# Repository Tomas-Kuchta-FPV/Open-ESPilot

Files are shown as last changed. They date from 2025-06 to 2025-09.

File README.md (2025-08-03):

# Open-ESPilot

This is a community-driven hardware project focused on creating an open and accessible Flight Controller (FC).   
The main focus is on being low-cost, availability, hackability and openness!  

Most of the Ardupilot FCs on the market are released by quite a huge brands that aren't OS and they cost a lot.  
That's why I've started this project to make an open-source and low-cost FC with the community.  

The target firmware is [ArduPilot](https://ardupilot.org/), which is a powerful open-source autopilot system.  

## Core Design Ideas
- *Dev board meets flight controller* hybrid
- Keep it budget-friendly
- Readily available components
- Hackability so you can hack on your features
- ❤️ Designed with care by and for the community

## What are the goals
The main one is a reference platform for devs and hackers. Then we can move to a product for the wider public.  

With the focus being on Hackability and Openness, there are endless possibilities for creativity!  
Here are a few ideas:
 - Prototyping and experimentation  
 - A low-cost alternative for those priced out of commercial FCs  
 - Teaching control theory and autonomous systems in schools  

## Why did I make it
I have a lot of experience with FPV drones running Betaflight.  

Then I started playing with the ESP32-based ArduPilot for almost three years. All of them were for a competition called Robotem Rovne.  
 - The first one is an autonomous rover which was breadboarded together. As with any other breadboard project, the wires were loose, they didn't make contact, and they were falling off.  
 - Then I made a second rover with an FC soldered on a proto board. Which worked wonderfully!  
 - Then I tried to make a PCB with a brushed motor controller. Not going to talk about this one. Didn't go as planned. :(  
 - After that, I've bought a SpeedyBee f405 WING FC and mounted it to an RC car. This is my Ardupilot learning platform.  

And now we are here. ...  
That was when I had the idea of making an ESP32 Flight Controller.  

## Future development
This is the first FC I made with the help of the community, so huge thanks to *everyone*. ♥️

### Ideas for future
 - modular system (eg, ELRS, GPS modules)
 - 30x30 FC for FPV drones. That's harder as there are plenty of great cheap FCs

## Project Status
**I have the PCB made, and now I need to order everything and test it!**
| PCB | Render |
| --- | --- |
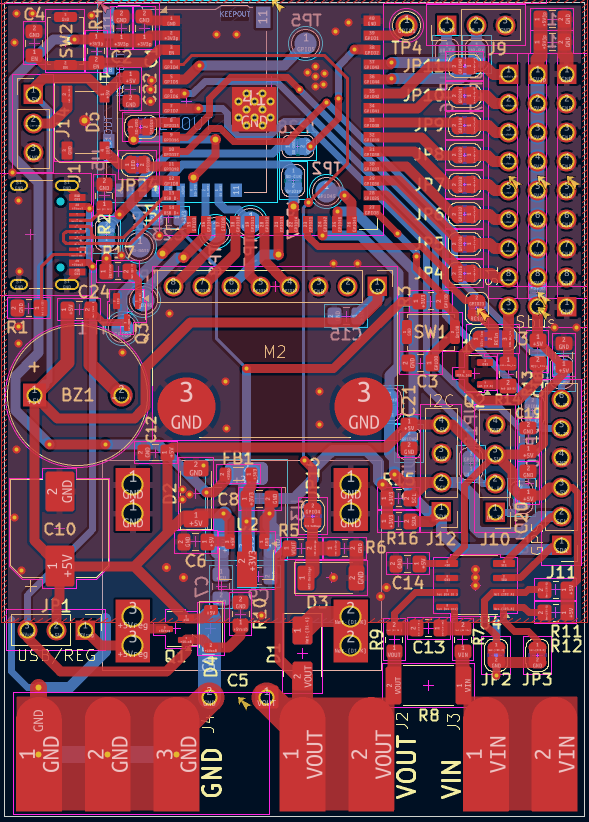
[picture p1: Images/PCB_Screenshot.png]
PCB Screenshot Front
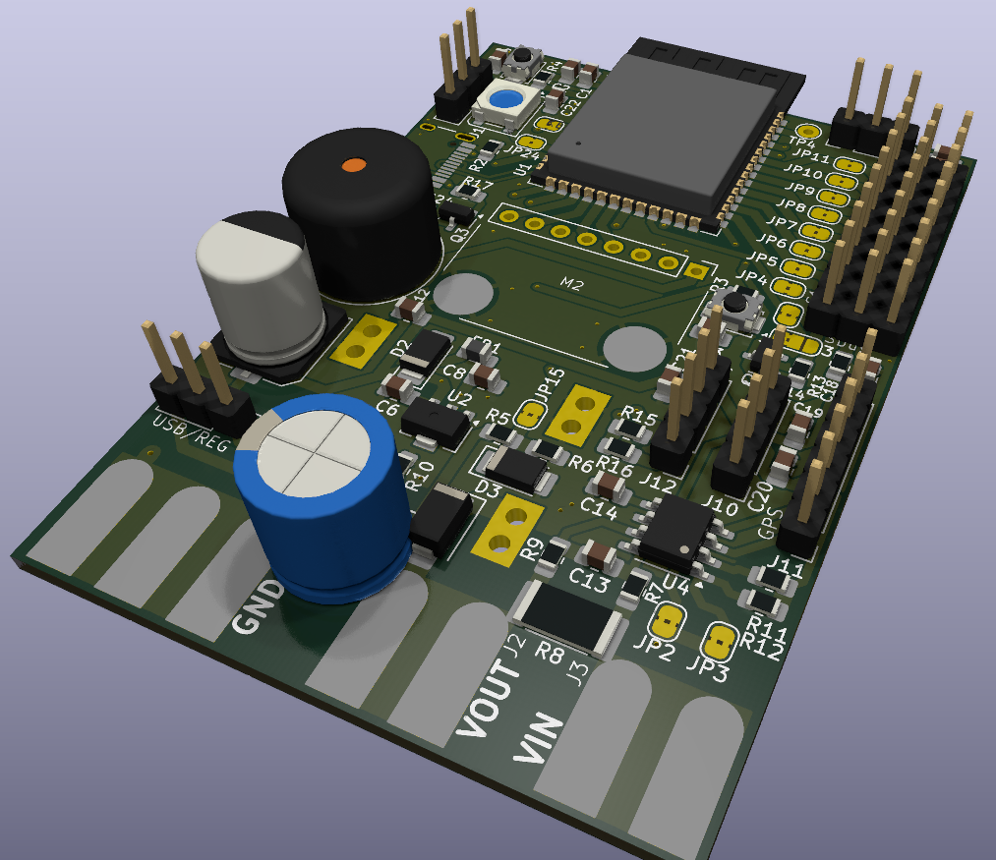
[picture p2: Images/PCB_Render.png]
PCB Render
|  |  |

### The Plan
- [x] Basic schematic and PCB layout
- [x] Selection of components is decided in [Issues](https://github.com/Tomas-Kuchta-FPV/Open-ESPilot/issues)
- [ ] Compare BOM cost to commercial FCs - going to figure it out when I have time.
- [ ] Complete code, documentation, and build guide

## Design Phases
1. **Planning & goal setting**✅
2. **Schematic design**✅
    - Start with core ESP32 + power
    - Add sensors and outputs
    - Evaluate BOM & gather feedback
3. **Community feedback loop**✅
4. **PCB layout**✅
5. **Prototype ordering**
6. **…And hopefully it works on the first try! 🤞**

## Firmware
We are now focusing on [ArduPilot ESP32 port](https://ardupilot.org/dev/docs/esp32-autopilot.html). They are making incredible work, and the project wouldn't exist without their hard work.  
I won't be able to write the code by myself, so huge props to the contributors! That's why I'm focusing on the HW.  
There are also possibilities for you to write your own code.  

## Contributing
We would love to hear feedback. We are open to everything, including issues, ideas and suggestions.  
That's why this project is Open Source.

## BOM
| Category | Qty | Price (USD) | Description | Link |
| --- | --- | --- | --- | --- |
| PCB component | 1 | 0.9 | TMB12A05 | https://lcsc.com/product-detail/Buzzers_Huaneng-TMB12A05_C96093.html |
| PCB component | 14  | 0.46 | 100nF | https://lcsc.com/product-detail/Multilayer-Ceramic-Capacitors-MLCC-SMD-SMT_YAGEO-CC0805KRX7R9BB104_C49678.html |
| PCB component | 7 | 0.11 | 22uF | https://lcsc.com/product-detail/Multilayer-Ceramic-Capacitors-MLCC-SMD-SMT_Samsung-Electro-Mechanics-CL21A226MQQNNNE_C5674.html |
| PCB component | 1 | 0.53 | 1000uF | https://lcsc.com/product-detail/Aluminum-Electrolytic-Capacitors-SMD_ROQANG-VT1A102M0810_C311227.html |
| PCB component | 1 | 0.57 | 1000uF (Leaded) | https://lcsc.com/product-detail/Aluminum-Electrolytic-Capacitors-Leaded_AISHI-ERR1VM102G20OT_C398835.html |
| PCB component | 1 | 0.57 | SS34 | https://lcsc.com/product-detail/Schottky-Diodes_MDD-Microdiode-Semiconductor-SS34_C8678.html |
| PCB component | 2 | 0.98 | PDZVTR5.1B | https://lcsc.com/product-detail/Zener-Diodes_ROHM-PDZVTR5-1B_C253499.html |
| PCB component | 1 | 0.84 | B5819W | https://lcsc.com/product-detail/Schottky-Diodes_MDD-Microdiode-Semiconductor-B5819W_C64885.html |
| PCB component | 1 | 0.49 | WS2812B LED | https://lcsc.com/product-detail/RGB-LEDs-Built-in-IC_XINGLIGHT-XL-5050RGBC-WS2812B_C2843785.html |
| PCB component | 1 | 0.22 | Ferrite Bead | https://lcsc.com/product-detail/Ferrite-Beads_TDK-MPZ2012S101AT000_C15957.html |
| PCB component | 1 | 0.87 | USB-C Receptacle | https://lcsc.com/product-detail/USB-Connectors_Korean-Hroparts-Elec-TYPE-C-31-M-12_C165948.html |
| PCB component | 1 | - | MP1584 module (clone) | https://www.aliexpress.com/item/1005005870392716.html |
| PCB component | 1 | - | GY-91 | https://www.aliexpress.com/item/32652866365.html |
| PCB component | 1 | 0.6 | AO3401A | https://lcsc.com/product-detail/MOSFETs_AOS-AO3401A_C15127.html |
| PCB component | 2 | 0.45 | BC847 | https://lcsc.com/product-detail/Bipolar-BJT_Nexperia-BC847B-215_C57668.html |
| PCB component | 2 | 0.21 | 5.1k | https://lcsc.com/product-detail/Chip-Resistor-Surface-Mount_YAGEO-RC0805FR-075K1L_C84375.html |
| PCB component | 2 | 0.19 | 10k | https://lcsc.com/product-detail/Chip-Resistor-Surface-Mount_YAGEO-RC0805FR-0710KL_C84376.html |
| PCB component | 1 | 0.21 | 1k | https://lcsc.com/product-detail/Chip-Resistor-Surface-Mount_YAGEO-RC0805FR-075K1L_C84375.html |
| PCB component | 5 | 0.19 | 10k | https://lcsc.com/product-detail/Chip-Resistor-Surface-Mount_YAGEO-RC0805FR-0710KL_C84376.html |
| PCB component | 2 | 0.49 | 10R | https://lcsc.com/product-detail/Chip-Resistor-Surface-Mount_YAGEO-RC0805FR-0710RL_C96347.html |
| PCB component | 1 | 0.41 | 0.5mΩ | https://lcsc.com/product-detail/Chip-Resistor-Surface-Mount_Viking-LR12FTDR0M50_C37635712.html |
| PCB component | 4 | 0.19 | 1k | https://lcsc.com/product-detail/Chip-Resistor-Surface-Mount_YAGEO-RC0805FR-071KL_C95781.html |
| PCB component | 2 | 0.63 | Push Button | https://lcsc.com/product-detail/Tactile-Switches_ALPSALPINE-SKRKAEE020_C115357.html |
| PCB component | 1 | 5.14 | ESP32-S3-WROOM-1-N8 | https://lcsc.com/product-detail/WiFi-Modules_ESPRESSIF-ESP32-S3-WROOM-1-N8_C2913198.html |
| PCB component | 1 | 0.87 | AMS1117-3.3 | https://lcsc.com/product-detail/Voltage-Regulators-Linear-Low-Drop-Out-LDO-Regulators_Advanced-Monolithic-Systems-AMS1117-3-3_C6186.html |
| PCB component | 1 | 0.41 | AMS1117-3.3 (Alt) | https://lcsc.com/product-detail/Voltage-Regulators-Linear-Low-Drop-Out-LDO-Regulators_Slkor-SLKORMICRO-Elec-AMS1117-3-3_C880752.html |
| PCB component | 1 | 2.84 | INA219 | https://lcsc.com/product-detail/Current-Sense-Amplifiers_TI-INA219AID_C1574856.html |
| PCB component | 1 | 1.32 | Micro SD Card Slot | https://lcsc.com/product-detail/SD-Card-Memory-Card-Connector_HRS-DM3AT-SF-PEJM5_C114218.html |
| PCB component | 50  | 0.46 | Pin Header (5x10) | https://lcsc.com/product-detail/Pin-Headers_BOOMELE-Boom-Precision-Elec-2-54-1-10P_C57369.html |
| PCB component | - | 13 | Shipping | - |
| PCB | - | 10.72 | PCB cost | https://cart.jlcpcb.com/quote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 |
| **TOTAL** | - | 50.97 | - | - |

## Built With
- [ESP32](https://www.espressif.com/en/products/socs/esp32) – the core MCU
- [KiCad](https://kicad.org/) – for PCB design
- [ArduPilot](https://github.com/ArduPilot/ardupilot) – the autopilot software we're building for
- ❤️ Open source tools and community support
- ... and Love ❤️

## License
Hardware: [CERN-OHL-W](https://ohwr.org/cern_ohl_w_v2.txt)  

Firmware: Ardupilot  

## Thanks
Many thanks to the amazing people who make [Hack Club](https://hackclub.com/) possible.
Thanks to Hack Club for inspiring so many people. I don't know the numbers, but maybe around thousands.  
Most of them are probably going to get a career from it. Love your work! ❤️  

And big thanks to the ArduPilot community for keeping robotics and autonomy Open and hackable.

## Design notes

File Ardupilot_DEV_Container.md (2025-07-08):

## Setup
```shell
podman run -dit --name ardupilot -v /home/host_computer/ardupilot:/ardupilot:z --userns=keep-id ubuntu
```

### exec as root and prepare
attach as root
```shell
podman exec -it --user root ardupilot bash
```

```shell
apt update
apt install passwd sudo

passwd root
passwd ubuntu

usermod -aG sudo ubuntu # or - adduser ubuntu sudo
# and exit
exit
```

```shell
podman stop ardupilot
```

## And now you can do
```shell
podman start -ai ardupilot # -ai is to attach to the terminal of the container
su ubuntu # to get the full login session
cd /ardupilot
```
now you can start to delvelop as usual

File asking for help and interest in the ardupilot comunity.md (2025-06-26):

## Moto
An OSHW, ESP32-based flight controller, built for affordability and flexibility!
## Goals setting message
### Goals of this message 
- Straight foward
- kinda short
- mension higway to HW
- to set goals

### What goals needs to be set
- Going to figure out GPIO breakout in the process
- [ ] MCU
	- needs to be the Module
	- ESP32 vs ESP32S3
- [ ] Which INS
	- Gyro, Accelometer
	- Barometer
	- Magnetometer is it needed?
- [ ] UARTs
	- One for connecting to the PC
	- Two HW for pheripeal
	- Can we use SW UARTs
- [ ] Inverted Sbus input?
- [ ] Elrs reciever connector like on the speedy bee F405
- [ ] USB-C
	- On board
	- Off board
- [ ] Does it really need Power monitoring?
	Altleast voltage monitoring as It Isnt hard to integrate
- [ ] GPIO breakout
### What design decisions need to be checked
- 6 servo outputs

### Should also ask
- is it reallycheaper?
- are people interested?

### The message
Hi evheryone 👋,
I'm tying to develop an ESP32 based flight controller. The main focus being on affordability and a robust development platform.
I'm delveloping this under Higway to hardware.
I would like it to be Open Source so the comunity can build it together.
I don't have as much experience in this port. I haven't also designed a lot of PCB boards, but I should be able to work it out. :)
So please can you help me decide which components I should use. Once I have the schematic I will give an update and ask if somebody has an idea of what to improve.

To give you a basic outline of what I'm planning:
- ESP32/S3 module seems logical, as using the bare chip would be too difficult to implement
- Almost the feel of a professional FC board of the likes of SpeedyBee F405 WING APP or  Mateksys F405 WING
- It will be only one board
- There will be one BEC

And now for the questions that would help with goal setting
1. ESP32 vs ESP32S3 module?
2. Which INS I should use?
	- I think that we need Gyro, Accel, Gyro
	- We don't nesserly need a Magnetometer as there are on GPSs.
	- GY-90 Does have multiple chips
	- ICM20XXX it seems better for this. Also the Baro needs to be decided.
3. UARTs
	- One for connection to the GCS
	- And other two hardware ones for Connecting to pheripeals
	- Can we use SofwareSerial?
4. Reciever connection
	- ELRS connection via header
	- Should I include inverted Sbus input?
5. USB-C connector
	- Onboard?
	- Offboard? Like on the SB F405 Wing.
6. Power monitoring
	- Voltage is super simple using a resitor divider - Going to implement it
	- Current is harder and more expensive. Please help me decide if I should Implement it.
7. GPIO breakout
	- How many exposed GPIOs?
	- One idea I had is that we can make modules like ELRS, GPS and etc.
	- Which form factor either ESP devoard or a custom one
		- ESP devboard form factor would be nice as we can use the modules for other projects
8. Form factor/layout style:
	- Sudgestion from AI.
	- I’m not fully decided yet, but I’ll aim to make the board as compact as reasonably possible.
	- Planning to keep the shape rectangular for easier mounting and compatibility.

If you are a dev for ESP32 please let me know and hopefully in over a monh I'll have the prototype in my hand. If it all goes to plan I would love to send you some boards.

#### AI remake

Hi everyone! 👋

I'm working on a project to develop an ESP32-based flight controller, focused on being affordable, hackable, and a solid development platform.

This is part of the Highway to Hardware initiative, and I want it to be open-source, so we can build it together as a community. 🚀

I’m still learning – I don’t have a ton of experience designing flight controllers or PCBs yet – but I’m motivated and slowly figuring things out!

Right now, I’m at the component selection stage and I’d love to hear your thoughts. Once I finish the schematic, I’ll post an update and ask for suggestions on how to improve.

---

**🔧 Design Goals & Ideas**
- ESP32 or ESP32-S3 module – simpler than using bare chips
- Inspired by boards like SpeedyBee F405 Wing APP or Mateksys F405 Wing
- Single-board design with 1x BEC
- Modular – plan to support external ELRS, GPS, and possibly other modules via headers
- Aiming for a “dev board meets flight controller” hybrid

**Things I’d love input on:**

1. MCU
	- ESP32 vs ESP32-S3?
	- Which one is better suited for this? Especially considering performance and future proofness?

2. IMU/INS selection:
	- We'd definitely need Gyroscope + Accelerometer
	- Not sure if a Magnetometer is needed (GPS modules often include one)
	- Thinking of the ICM20XXX family over older combo boards like GY-90 as they have more chips
	- Also open to Barometer suggestions

3. UARTs:
	- Plan to use:
	- 1 for telemetry (GCS)
	- 2 for peripherals (GPS, receiver, etc.)
	- Is SoftwareSerial implemented or can it be used?

4. Receiver input:
	- ELRS header support like on the SB F405 WING
	- Should I also add an inverted SBUS input for compatibility?

5. USB-C connector:
	- Should the USB-C be onboard, like on most ESP32 dev boards?
	- Or offboard, like on SpeedyBee-style boards with a connector on a cable?
	- Or maybe a hybrid approach – onboard USB-C by default, but with solder pads available for hacking in an off-board connector if needed?

6. Power monitoring:
	- Voltage sensing via resistor divider is easy – will add
	- Current sensing is more complex and costly – should I include it?

7. GPIO breakout:
	- How many exposed GPIOs?
	- One idea I had is that we can make modules like ELRS, GPS and etc.	- Which form factor either ESP devboard or a custom one
		- ESP devboard form factor would be nice as we can use the modules for other projects

8. Form factor/layout style:
	- I’m not fully decided yet, but I’ll aim to make the board as compact as reasonably possible.
	- Planning to keep the shape rectangular for easier mounting and compatibility.

---

📝 **Follow the Project**
You can track progress, view schematics, and join the discussion on GitHub:
👉 [Open-ESPilot Repository](https://github.com/Tomas-Kuchta-FPV/Open-ESPilot)
I’ll be posting regular updates there, including design files, dev notes, and future testing results. Feel free to open issues or share your ideas!

If you're into ESP32 dev or just excited about this sort of project, I’d love to hear from you!
If all goes to plan, I hope to have a prototype in hand within a month 🤞
And if things go well, I’d love to share a few boards with interested testers. 😊

I’m not a native English speaker, so I used AI (ChatGPT) to help me rephrase my original idea more clearly and friendly. The raw version is in my JOURNAL.md if you're curious. :)

Thanks for reading and helping shape this little adventure!

— Tomáš

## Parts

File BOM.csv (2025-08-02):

Category | Ref. Designator | Qty | Price (USD) | Description | LCSC Code | Link
PCB component | BZ1 | 1 | 0.9 | TMB12A05 | C96093 | https://lcsc.com/product-detail/Buzzers_Huaneng-TMB12A05_C96093.html
PCB component | C1, C3–C24 | 14 | 0.46 | 100nF | C49678 | https://lcsc.com/product-detail/Multilayer-Ceramic-Capacitors-MLCC-SMD-SMT_YAGEO-CC0805KRX7R9BB104_C49678.html
PCB component | C2, C4, C6–C9, C16 | 7 | 0.11 | 22uF | C5674 | https://lcsc.com/product-detail/Multilayer-Ceramic-Capacitors-MLCC-SMD-SMT_Samsung-Electro-Mechanics-CL21A226MQQNNNE_C5674.html
PCB component | C5 | 1 | 0.53 | 1000uF | C311227 | https://lcsc.com/product-detail/Aluminum-Electrolytic-Capacitors-SMD_ROQANG-VT1A102M0810_C311227.html
PCB component | C10 | 1 | 0.57 | 1000uF (Leaded) | C398835 | https://lcsc.com/product-detail/Aluminum-Electrolytic-Capacitors-Leaded_AISHI-ERR1VM102G20OT_C398835.html
PCB component | D1 | 1 | 0.57 | SS34 | C8678 | https://lcsc.com/product-detail/Schottky-Diodes_MDD-Microdiode-Semiconductor-SS34_C8678.html
PCB component | D2, D3 | 2 | 0.98 | PDZVTR5.1B | C253499 | https://lcsc.com/product-detail/Zener-Diodes_ROHM-PDZVTR5-1B_C253499.html
PCB component | D4 | 1 | 0.84 | B5819W | C64885 | https://lcsc.com/product-detail/Schottky-Diodes_MDD-Microdiode-Semiconductor-B5819W_C64885.html
PCB component | D5 | 1 | 0.49 | WS2812B LED | C2843785 | https://lcsc.com/product-detail/RGB-LEDs-Built-in-IC_XINGLIGHT-XL-5050RGBC-WS2812B_C2843785.html
PCB component | FB1 | 1 | 0.22 | Ferrite Bead | C15957 | https://lcsc.com/product-detail/Ferrite-Beads_TDK-MPZ2012S101AT000_C15957.html
PCB component | J1 | 1 | 0.87 | USB-C Receptacle | C165948 | https://lcsc.com/product-detail/USB-Connectors_Korean-Hroparts-Elec-TYPE-C-31-M-12_C165948.html
PCB component | M1 | 1 | 3.3 | MP1584 module (clone) | - | https://www.aliexpress.com/item/1005005870392716.html
PCB component | M2 | 1 | 2.8 | GY-91 | - | https://www.aliexpress.com/item/32652866365.html
PCB component | Q1 | 1 | 0.6 | AO3401A | C15127 | https://lcsc.com/product-detail/MOSFETs_AOS-AO3401A_C15127.html
PCB component | Q2, Q3 | 2 | 0.45 | BC847 | C57668 | https://lcsc.com/product-detail/Bipolar-BJT_Nexperia-BC847B-215_C57668.html
PCB component | R1, R2 | 2 | 0.21 | 5.1k | C84375 | https://lcsc.com/product-detail/Chip-Resistor-Surface-Mount_YAGEO-RC0805FR-075K1L_C84375.html
PCB component | R3, R4 | 2 | 0.19 | 10k | C84376 | https://lcsc.com/product-detail/Chip-Resistor-Surface-Mount_YAGEO-RC0805FR-0710KL_C84376.html
PCB component | R5 | 1 | 0.21 | 1k | C84375 | https://lcsc.com/product-detail/Chip-Resistor-Surface-Mount_YAGEO-RC0805FR-075K1L_C84375.html
PCB component | R6, R10–R13 | 5 | 0.19 | 10k | C84376 | https://lcsc.com/product-detail/Chip-Resistor-Surface-Mount_YAGEO-RC0805FR-0710KL_C84376.html
PCB component | R7, R9 | 2 | 0.49 | 10R | C96347 | https://lcsc.com/product-detail/Chip-Resistor-Surface-Mount_YAGEO-RC0805FR-0710RL_C96347.html
PCB component | R8 | 1 | 0.41 | 0.5mΩ | C37635712 | https://lcsc.com/product-detail/Chip-Resistor-Surface-Mount_Viking-LR12FTDR0M50_C37635712.html
PCB component | R14–R17 | 4 | 0.19 | 1k | C95781 | https://lcsc.com/product-detail/Chip-Resistor-Surface-Mount_YAGEO-RC0805FR-071KL_C95781.html
PCB component | SW1, SW2 | 2 | 0.63 | Push Button | C115357 | https://lcsc.com/product-detail/Tactile-Switches_ALPSALPINE-SKRKAEE020_C115357.html
PCB component | U1 | 1 | 5.14 | ESP32-S3-WROOM-1-N8 | C2913198 | https://lcsc.com/product-detail/WiFi-Modules_ESPRESSIF-ESP32-S3-WROOM-1-N8_C2913198.html
PCB component | U2 | 1 | 0.87 | AMS1117-3.3 | C6186 | https://lcsc.com/product-detail/Voltage-Regulators-Linear-Low-Drop-Out-LDO-Regulators_Advanced-Monolithic-Systems-AMS1117-3-3_C6186.html
PCB component | U3 | 1 | 0.41 | AMS1117-3.3 (Alt) | C880752 | https://lcsc.com/product-detail/Voltage-Regulators-Linear-Low-Drop-Out-LDO-Regulators_Slkor-SLKORMICRO-Elec-AMS1117-3-3_C880752.html
PCB component | U4 | 1 | 2.84 | INA219 | C1574856 | https://lcsc.com/product-detail/Current-Sense-Amplifiers_TI-INA219AID_C1574856.html
PCB component | U5 | 1 | 1.32 | Micro SD Card Slot | C114218 | https://lcsc.com/product-detail/SD-Card-Memory-Card-Connector_HRS-DM3AT-SF-PEJM5_C114218.html
PCB component | Headers | 50 | 0.46 | Pin Header (5x10) | C57369 | https://lcsc.com/product-detail/Pin-Headers_BOOMELE-Boom-Precision-Elec-2-54-1-10P_C57369.html
PCB components | - | - | 13 | Shipping | - | -
PCB components | - | - | ~8.6 | VAT (DPH and CLO) | - | -
PCB components | - | - | 4.58 | Czech post vat processing cost | - | https://www.ceskaposta.cz/zmeny-pri-dovozu-zasilek-nizke-hodnoty
PCB | - | - | 10.72 | PCB cost | - | https://cart.jlcpcb.com/quote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
TOTAL | - | - | 55.55 | - | - | -

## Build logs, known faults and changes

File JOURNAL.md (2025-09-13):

---
title: "OPEN-ESPilot"
author: "Tomas Kuchta"
description: "An OSHW, ESP32-based flight controller, built for affordability, flexibility!"
created_at: "2025-07-21"
---

**Total Time Spent on designing: 55h**
**Total Time Spent: 55+x h**

> English isn't my first language, so feel free to point out any mistakes or unclear parts.

## Written README.md - 21.6.2025  
Like every begining of a Open Source project I create a GitHub repo and write a readme to let people know on what I'm working on.

**Time spent: 1h**

## Goal setting and asking for help and interest in the ardupilot comunity. - 26.6.2025  
I have written out a list of things I would need help with. And did simple goal setting to see if people like my idea.  
Then written a message and posted it on [ardupilot discussion forum.](https://discuss.ardupilot.org/t/help-me-build-the-first-open-source-esp32-flight-controller-for-makers/135974)  
Also I wanted to ask the devs on the Discord channel so I have also messaged them.  
I'm thankful for any help from the community as I have some perception but community needs can be other. When workng together we can make useful things for more people!

I have created Issues for each goal in this repo to keep ideas in one place.  
After that I have created issues for thing that needs to be decided on.  
I'm sharing my notes for the message in [asking for help and interest in the ardupilot comunity.md](https://github.com/Tomas-Kuchta-FPV/Open-ESPilot/blob/41703091e80cd6ef6a6719e9a7e344e687c4ec42/asking%20for%20help%20and%20interest%20in%20the%20ardupilot%20comunity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)

**Time spent: 3h**

## Talked with DavidBuzz and asked for help, laid ground work for ESP32S3 core schematic and Pin definitions. - 28.6.2025  
I have read a lot of great responses to the message. Thank everyone for support.

We have decided on a form factor of a plane FC. Because this is my First FC and I didn't want to complicate it.  
David had an interesting idea to make it 30x30 Drone form factor. But that would need a two sided components and more than 4 layers. So that will hopefully be project for another day. I love this idea.

This sparked an idea of the first design constraints, which are Inexpensiveness, availability and hackability(flexibility)!

With the help of David we have decided on a MCU [ESP32-S3-WROOM-1-N8](https://lcsc.com/product-detail/WiFi-Modules_Espressif-Systems-ESP32-S3-WROOM-1-N8_C2913198.html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).  
We think that you should be able to fit the AP code on 4mb flash but this project is aimed at more of a Dev board/Flight Controller hybrid so we were thinking of either 16mb or 8mb flash and no PSRAM as it isn't needed. And the 8mb hit that sweet spot of price and developer needs.  
He has also pointed me to his [pin definition](https://github.com/davidbuzz/ardupilot/blob/esp32s3-buzz-combined-sept-11th/libraries/AP_HAL_ESP32/README.esp32s3-pin-selection-hints.txt). And I have compiled the definitions into a spreadsheet.

He said that I completly forgot the SD card. So I have opened an issue for it.

Also I have deleted my work so I needed to recover it. 🤦 - Commit 6e2a837

Then I have edited the README.md to reflect the design constraints. To let everyone know about what is this project!

**Time spent: 4h**

## Finished the ESP32S3 and its peripherals and Finished Power side of things. - 30.6.2025  
I started by researching how to implement the ESP32-S3 WROOM module. Since I’ve previously worked with the ESP32-C3, I already have some background knowledge.  
During this phase, I also learned about KiCad buses and hierarchical schematic design.

I have made the schematic with the MP1584 IC because I thought there are modules based on this IC but after desoldering the chip. It didn't really look like the correct footprint so I have deleted it because it would be too much work. ... I've said after I have made a schematic symbol and implemented it to the schematic with its components.

So I have decided to use the *Clone "MP1584" module* thats at least how do I call them. Because this way its way easier and probably cheaper as I would either need to either desolder the chip from the board or buy it separately. So Module will help a lot in terms of cost and simplicity.

So after all of that I have created another set of schematic symbol and footprint. This took tooooo looooong. At least it's done.

And made the schematic prettier. :]

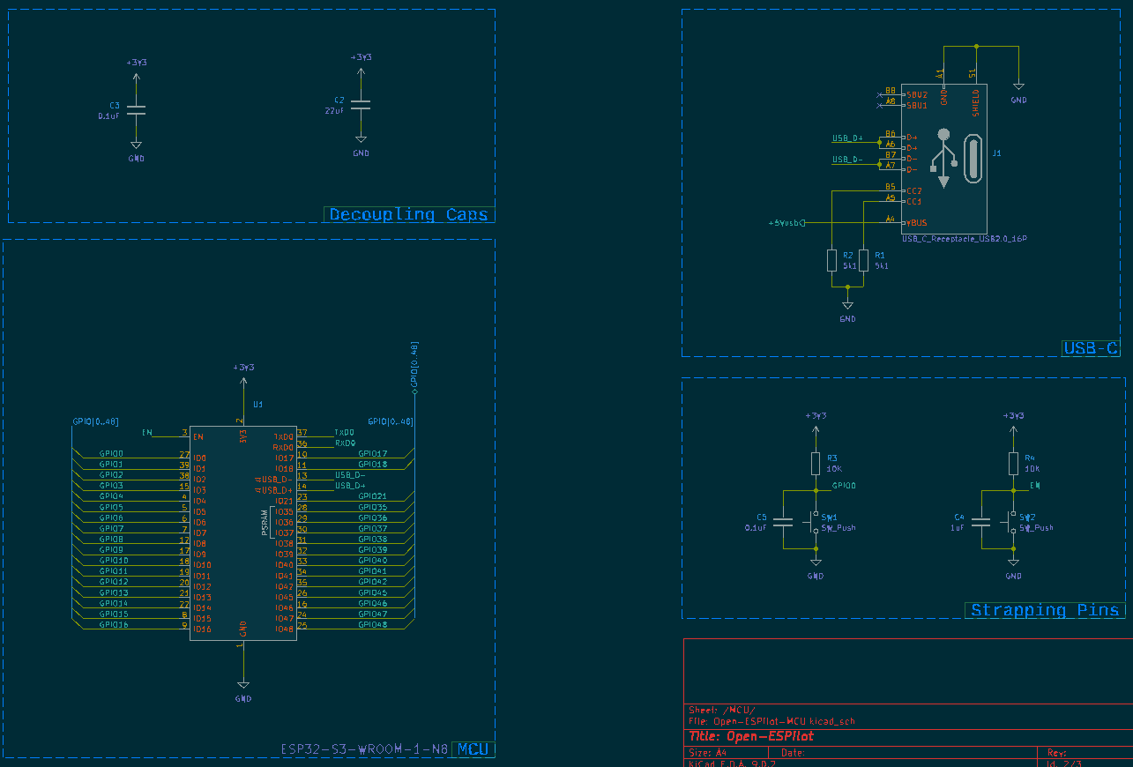
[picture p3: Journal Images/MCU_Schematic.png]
MCU Schematic

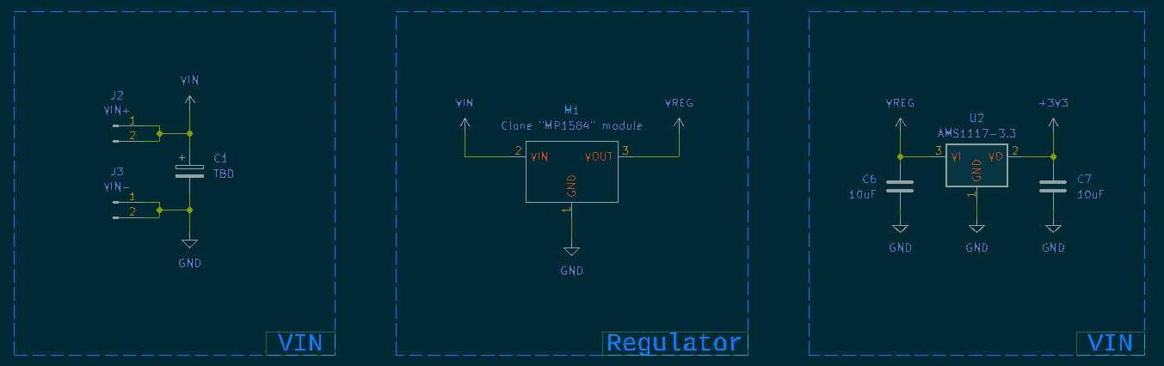
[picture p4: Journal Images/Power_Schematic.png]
Power Schematic

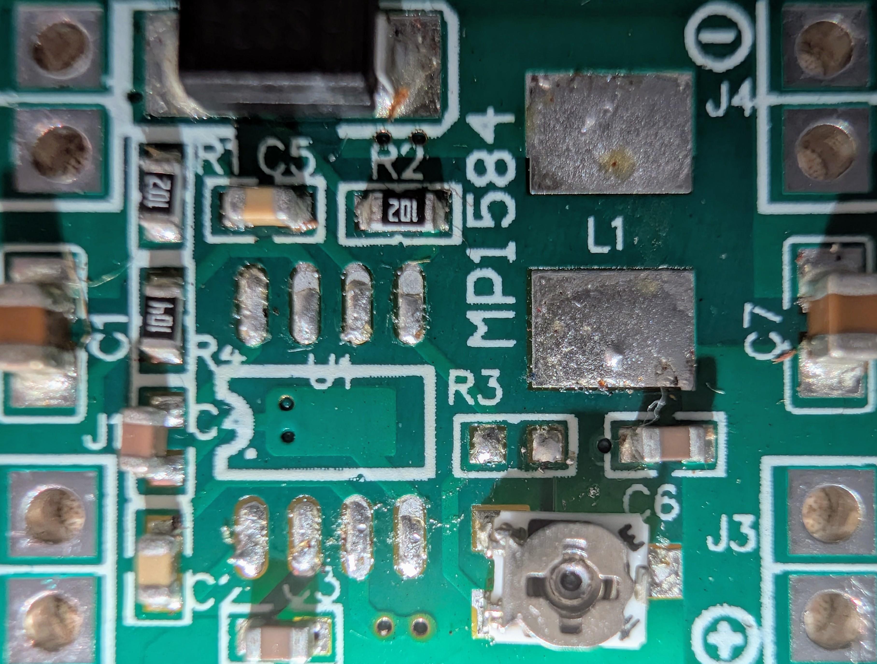
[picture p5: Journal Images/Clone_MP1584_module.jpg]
MCU Clone MP1584 module


**Time spent: 5h**

## Added Schematic and footprint of the GY-91 IMU and implemented it to the schematic. - 1.7.2025  
Today I haven't much time to work on this project so I had Just one goal of implementing IMU which is the GY-91 module.  
Its Going to be used as a module on the board because I'm implying same philosophy as for the *Clone "MP1584" module*.

I always like the schematic symbol creation in KiCAD. But creating the footprint is much more frustrating as I can't use normal CAD tools to constrain the footprint. I would love to make footprints in FreeCAD, maybe there is a better worflow?

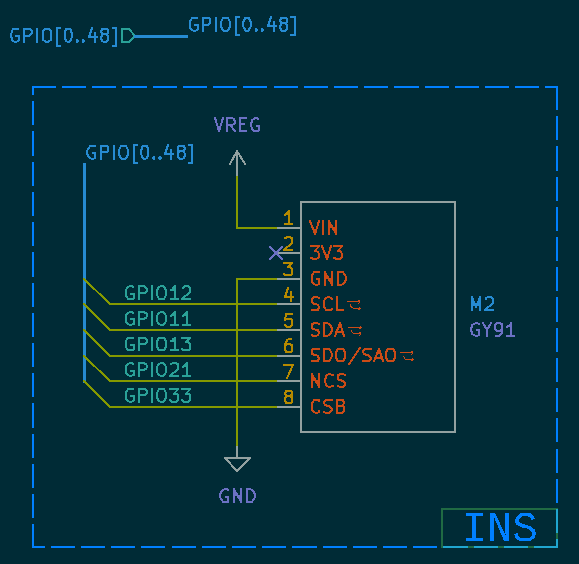
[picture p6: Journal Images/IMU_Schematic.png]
IMU


**Time spent: 3h**

**Check if the footprint is correct using a paper representation. - 3.7.2025**  
Today I haven't had much time so I only checked if the footprints I've made are correct by printing them on paper.  
But when exporting I've noticed that I forgor the front silkscreen. So this should be corrected when I have time.  
After printing the first sheet it printed in portrait and it was shrinked.  
Then I printed it in landscape and after confirming with calipers it was shrieked a little which didn't matter. Aleast I can check the proportions which seemed to be correct.

After checking everything seemed to be OK except for the F. Silkscreen.

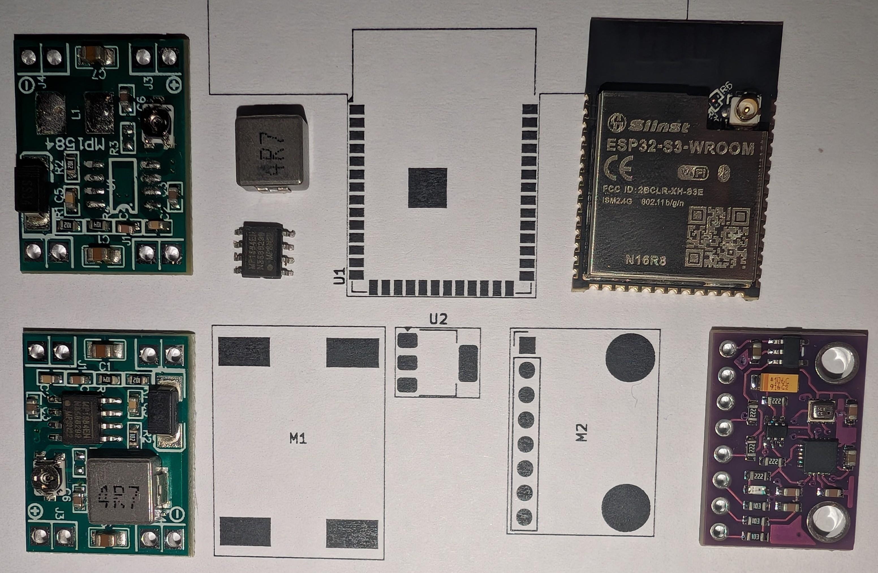
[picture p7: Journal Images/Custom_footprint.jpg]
Custom Footprint


**Time spent: 2h**

## Assigned pins to the ESP pins and tested it by compiling adupilot code. - 7.7.2025  
After reading a lot of documentation and Davids Pin definition I have created a LibreOffice Calc sheet to write my notes and GPIO pin assigments.  
I have learned that the pins for the [sd card in mmc mode can't be reassigned](https://github.com/ArduPilot/ardupilot/blob/eeb72ce9622dbe6a5dda6ae1cb8352c0c00750f9/libraries/AP_HAL_ESP32/SdCard.cpp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).
[And the SPI3 controller can bypass GPIO Matrix to improve preformance.](https://github.com/davidbuzz/ardupilot/blob/8875cd8d980312bfe78d42909fcda2e10fdb5c46/libraries/AP_HAL_ESP32/README.esp32s3-pin-selection-hints.txt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) As of now I don't think is implemented in ardupilot code. One issue I see is that the GPIO pins are all over the place and the routing will be more difficult.  
So I kept these in mind and worked around them. 

### Compiling Ardupilot  
For now I just assigned pins to the important Devices.  
I have tested the ardupilot port to the ESP32 platform in the past. I was using the ESP32 with a GY-91 IMU. For that I have prepared a podman container.  
I'm sharing the secret sauce in [Ardupilot_DEV_Container.md](https://github.com/Tomas-Kuchta-FPV/Open-ESPilot/blob/main/Ardupilot_DEV_Container.md)  
So I have compiledd and tested the esp32s3empty board definition and it worked! Although I haven't seen anythyng on the PWM outputs which is probably fine right? Then I have tested an ibus protocol. There was a error `E rmt(legacy): RMT RX BUFFER FULL`. [And in esp32empty there was a coment on that.](https://github.com/ArduPilot/ardupilot/blob/eeb72ce9622dbe6a5dda6ae1cb8352c0c00750f9/libraries/AP_HAL_ESP32/boards/esp32empty.h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) I can't bother with code now as I don't have too much time as we go 12. in a mountain cabbin and I want to be offline and present in the moment. :)  

Thing I have probed with a scope
 - IMU comunication ☑
 - I2C ☑
 - MMC SD card ☑
 - PWM outputs 𐄂 - This is weird but I think the problem is on my side.

### Assigning Pins  
After that I have thought on how to assign the GPIOs because I need to think about if I can route the PCB and if I can even use the pins I choose.  
Luckily I'm working with an ESP32 platform which has the mentioned GPIO matrix that makes the assigment a whole lot easier as I can switch some pins for one and the other when routing the PCB. After almost completing the assigment I had a briliant idea to color code the GPIOs so I know which side is which.  
During the design I've referenced the [ESP32-S3-WROOM-1](https://www.espressif.com/sites/default/files/documentation/esp32-s3-wroom-1_wroom-1u_datasheet_en.pdf) datasheet. So I know if the pins I choose are one next to each other.  

I now can tell you why I have assigned the pins this way.  
| Component  | Decision |
| --- | --- |
| GY-91 | Pin specific if bypasing GPIO matrix. So with Davids recomendation we choose these pins. |
| SD card | If using the faster SD MMC mode the pins are assigned to specific pins. |
| PWM output | It needed to be unsplit and to be on a convinient side of the module so I choose the right side. |

 - The other periphelials were chosen as it fit. The main consideration was for the pins that needed to be together.

Then I have created a sketch of the board layout. I'm using the kicad color scheme to know how much will the traces cross.

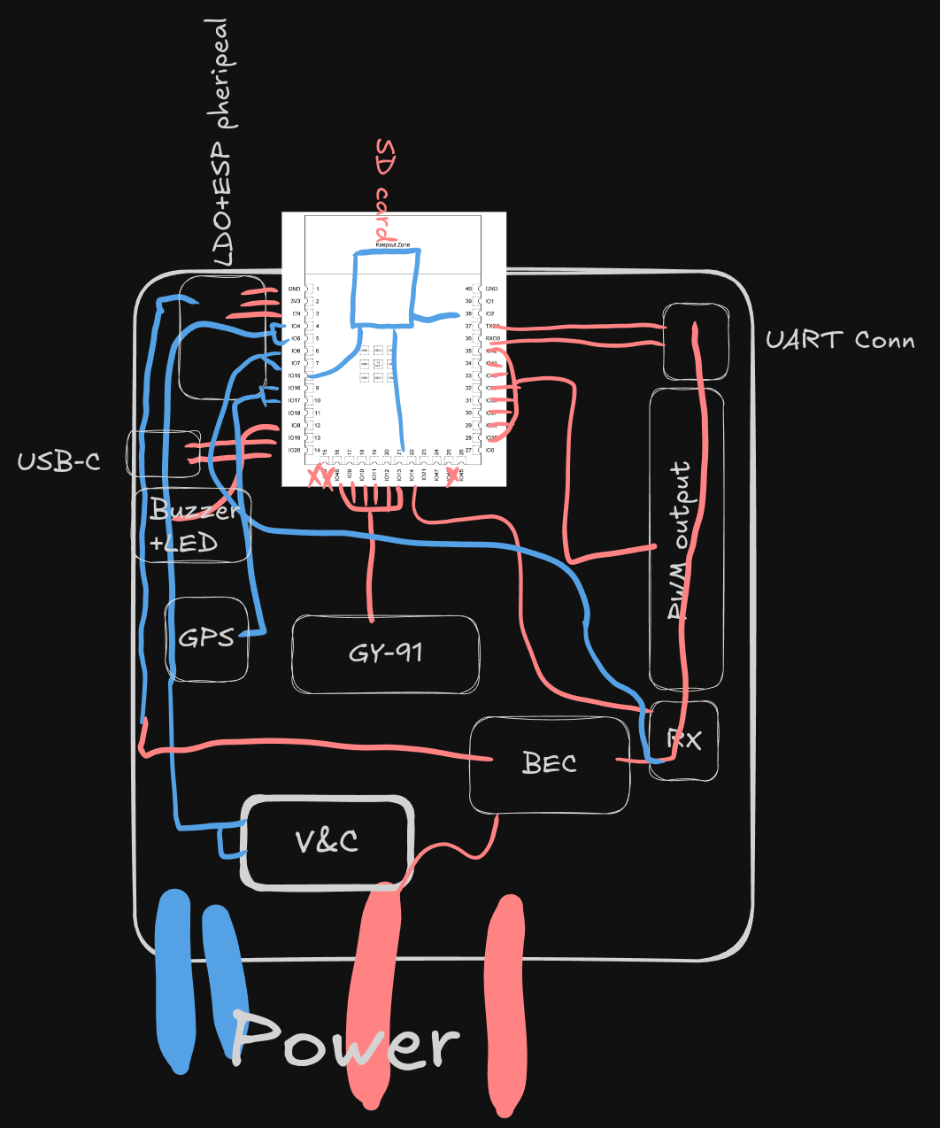
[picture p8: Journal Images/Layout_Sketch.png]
Layout Sketch


Also there is the spreadsheet:  
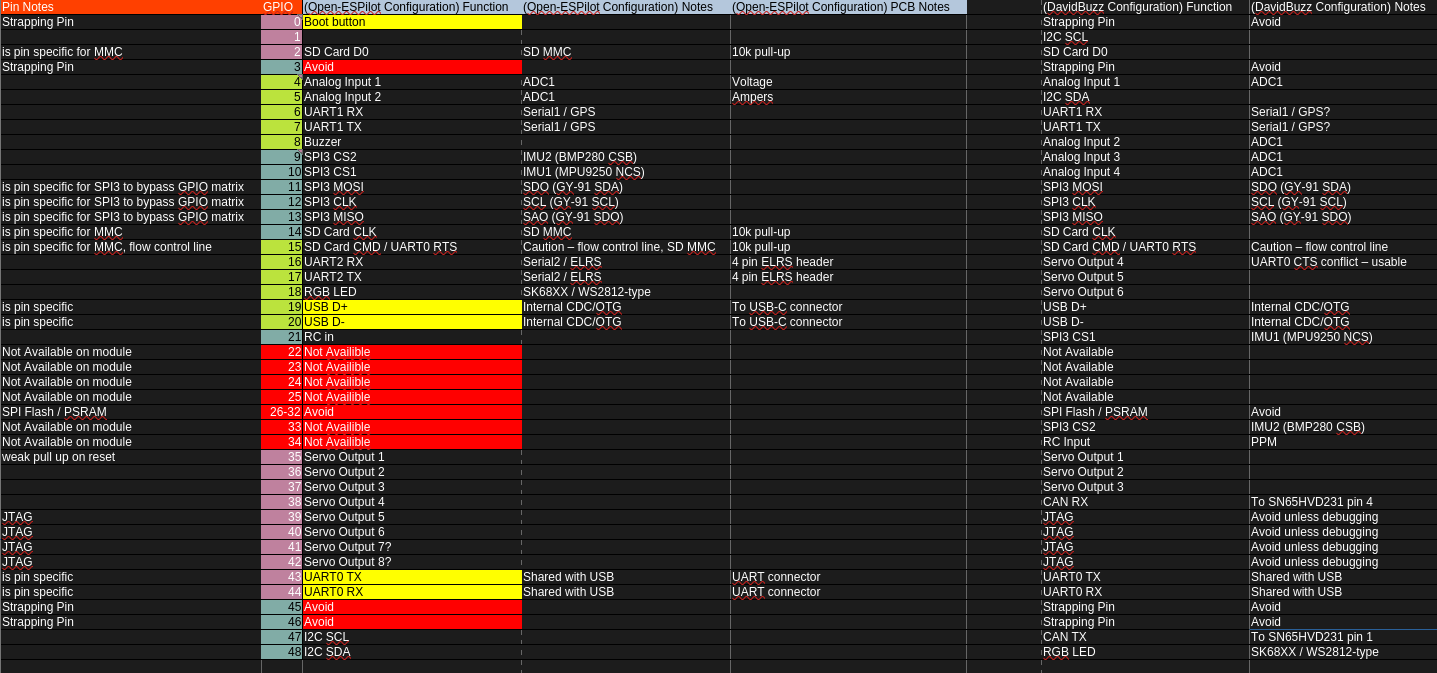
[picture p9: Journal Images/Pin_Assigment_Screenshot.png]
Pin Assigment Screenshot


**Time spent: 8h**

## Added peripheral to the schematic. - 12.7.2025  
After assigning the pins I need to add peripherals to the shematic. Which is pretty easy as I already have assigned pins in a spreadsheet.  
I'm working on this on a family trip in Krkonoše mountains in my free time. Thats why this part took me a long time.  
I have referenced the ardupilot on ESP32 documentation and a generic f405 wing FC. So that the pinouts are common.  

  - I have started with checking if the MCU is correct.  
  - Then I went on the PWM out and RC in.  
    - I have used a common pinout for the PWM connector.  
    - After that I have Added the RC in connector with an invertor for SBUS.  
  - UARTs are next.  
    - For the GPS I just used a common pinout thats used for M10 GPS.  
    - And the ELRS I just used a generic f405 wing for the pinout.  
  - For I2C I just used the pinout from ardupilot on ESP32.  
  - RGB LED and the BUZZER was pretty easy as for the buzzer I just used a simple tranzistor switch.  
  - As for the micro SD card I have no clue as I didn't worked with SD cards.  
    - So I just used the recemonded pins.  
  - Then I have thought and implemented Voltage and Current measurement tracked in [issues #6](https://github.com/Tomas-Kuchta-FPV/Open-ESPilot/issues/6).  
    - Voltage is pretty simple as I can just use a voltage devider and read the scaled voltage.  
    - But for Current I have a few options like:  
      - Shunt Resistor + Amplifier  
        - OP amp  
        - INA219 - Current/Power Monitor With I2C Interface  
        - INA181 - Current-Sense Amplifier  
      - Hall Effect Sensors  
    - So I have opted for a voltage devided and a INA219 IC.  
    - The INA219 isn't implemented in ardupilot on ESP32 yet so thats why there is also retundant voltage divider. The INA219 circuit can be left out.  

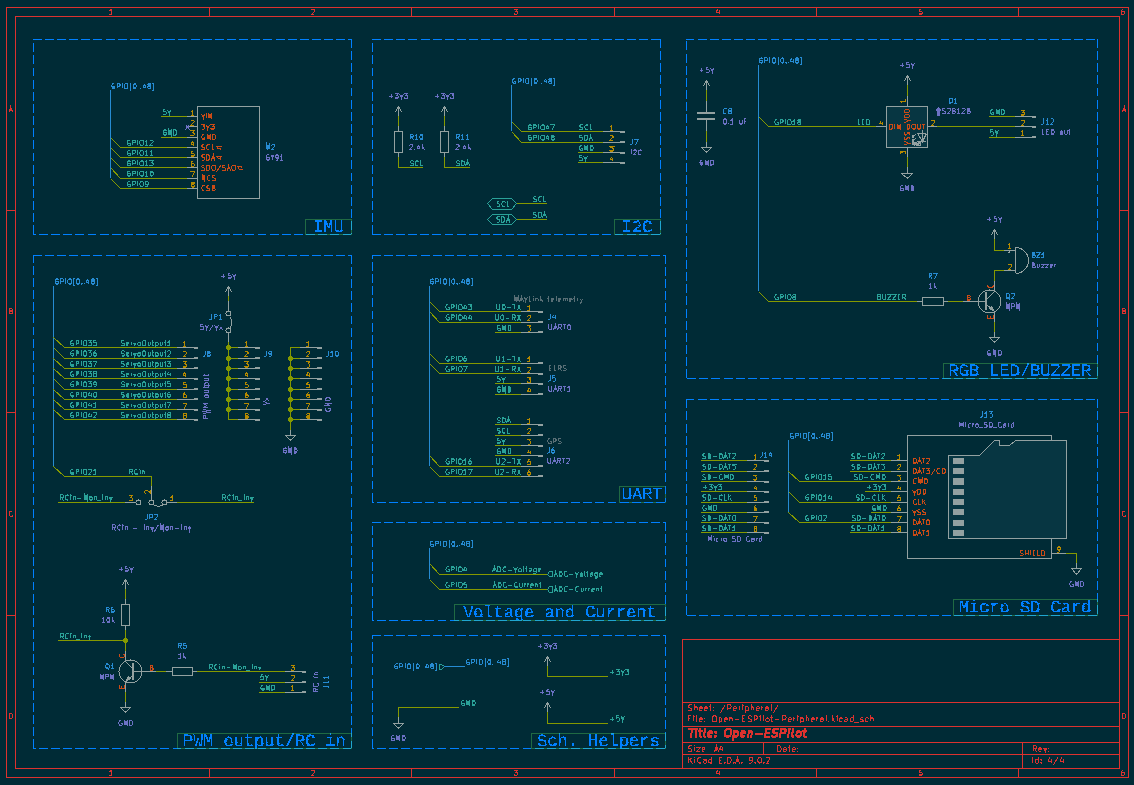
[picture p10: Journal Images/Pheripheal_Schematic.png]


**Time spent: 5h**

## Fixing mistakes in my Schematic - 16.7.2025  
I have pretified and clarified the ROOT schematic. And wired it using hirarchical pins. I don't know whats better for clarity. I'm thinking either hirarchical pins or global labels.  
I've also made a voltage selector with a p-mosfet and a retundant 3 pin header to select either the regulator or the USB-C.

After that I've checked with Electrical Rules Checker. And it showed a lot of errors and warnings.  
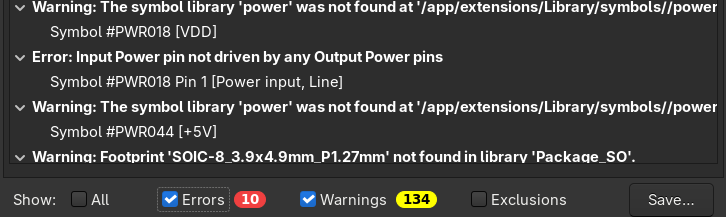
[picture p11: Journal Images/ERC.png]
ERC
  
One of those thing was that I've added two net labels to one wire as I want to label the gpio and function.  
Also some Power pins errors.  
OOOH it was just because the libraries wasn't loaded. Now its just 10 errors and 22 warnings. nice ;)  

Then I went on making the schematic better.  
Things edited:  
 - Added a resistor for a bridged solder jumper on the double net labels wires to separate nets and make the traces easily separable.  
 - Added GPIO termination pins  
 - Added more Capacitors  
 - Added ESD protection on +5V line  
 - Added a polyfuse and reverse voltage protection diode  
 - Added a zener diode to ADC voltage measurement  
 - Added a second LDO - to test a smaller LDO  
 - Renamed the Clone `"MP1584" module` to `Clone _MP1584_ module` as it caused some issues  
 - And also running the voltages to and from on the root schematic insted of in global power symbols  

After procrastinating I have to fix the other errors I have with the schematic.  
OH now there are just errors that arent as severe. nice  

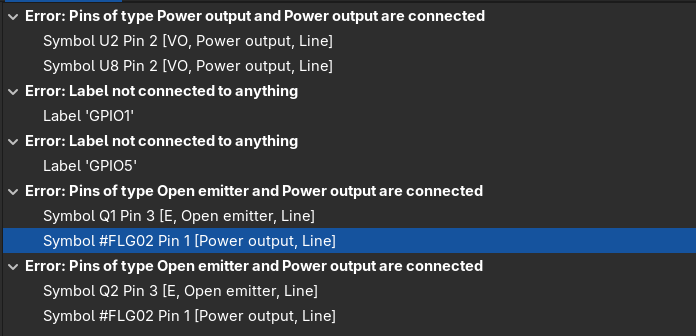
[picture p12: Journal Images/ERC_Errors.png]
ERC Errors

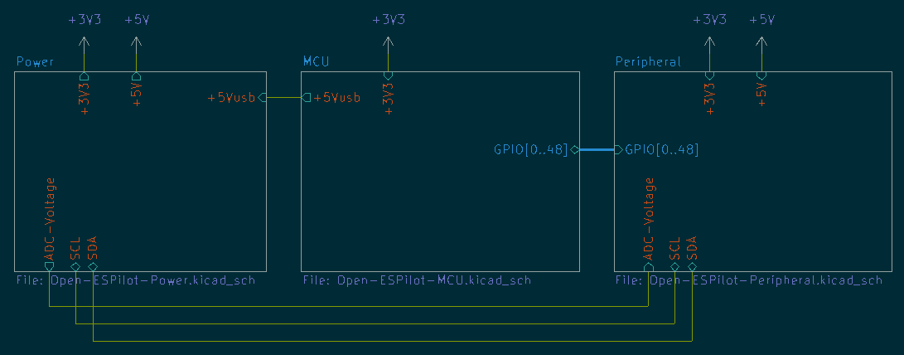
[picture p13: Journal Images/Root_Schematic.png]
Root Schematic


**Time spent: 5h**

## Assigning footprints and compents to schematic symbols. - 19.-30.7.2025  
When fixing issues with my schematic in the process of adding jumpers I have already decided on footprints.  
So everything else remains.  
I haven't thought about the footprints and components a lot.  
So the first obvious ones are resistors and capacitors. Keeping with the project theme (Inexpensiveness, availability and hackability) I choose the 0805 SMD size as it can be easily soldered and you can go to a smaller size like 0402 which still fits on the pads.  
I have referenced my other project called TwinkleTron for footprints and componets. For example the USB-C, Buttons, smaller SOT-89-3 LDO. And replicated my 5V Selector as I have worked on multiplexing voltage before. There is no need to reinvent the wheel.  

After that I have removed the polyfuse from the vin to the regulator. And now I have 5V protected and unprotected with the polyfuse.  
Then I have removed the polyfuse entirely as I couldn't find the right fuse.

And back to the main task. 
For the breakout I have decided to have a pin header compatible plated hole.  
The buzzer I choose a common `TMB12A05` buzzer that has diameter of 12mm and pitch of 7.6mm.  
For the micro SD card I went with `DM3AT-SF-PEJM5` that was already in KiCAD and I have looked on LCSC and there weren't any better options.  
And the Gold Caps I choose 1000uF leaded for the input. And 1000uF SMD for the 5Vc rail as I expect a lot of noise there from the servos. So I have added a cap to the servos and to peripheals. Also I have noticed that i forgot decoupling caps.  

Now I need to assign three things the shunt resistor, the power solder pads and decoupling caps.  
For the solder pads I got inspired from the SB f405 WING APP FC and decided on long rectangular pad insted of sqare one from Matek.  
As in KiCAD there isn't a footprint that would fit I need to make one. It was pretty straight foward.  
I choose the pad size and I wanted to have one side with rounded edges so I've choose chamfered with other corners rounded and the chamfer size as small at it can be and corner size on 50%. Also chose the corners to "chamfer".  
For the decoupling caps I choose common 100nF and 22uF MLCCs. (I like the name;)  
AS for the shunt resistor I need to read the `INA219`s documentation a little more.  
I have asked claude to choose the [Shunt resistor](https://claude.ai/share/db22d6e2-1d00-4bdb-a14f-e951676a770c) because I donn't have any experience with shunts. I have thought to use either a 1mR or 0.5mR one. The 0.5mR seems better.  
Also because the FC is qite mission critical I've added a ferrite bead to the ESP32S3 to hopefully filter noise out. Maybe it would be beneficial to have more than one regulator.  

After all of that I check ERC and don't see any error. yay :)  
So that means that the schematic is complete!  

Now I need to route the PCB. Also I need to notify the comunity that the schematic is finished!  

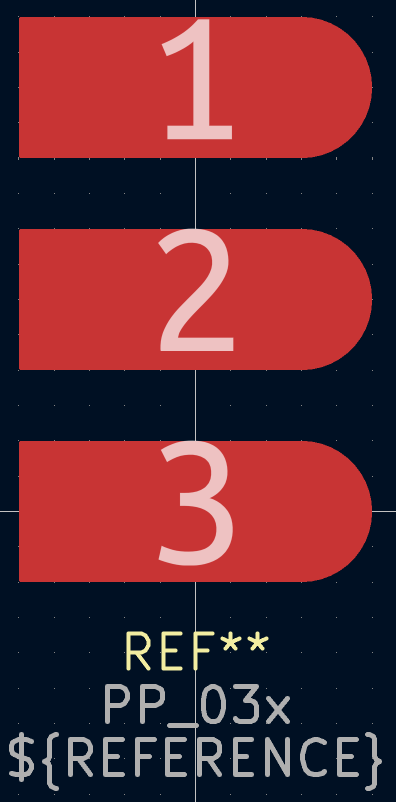
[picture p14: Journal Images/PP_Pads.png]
PP Pads
  

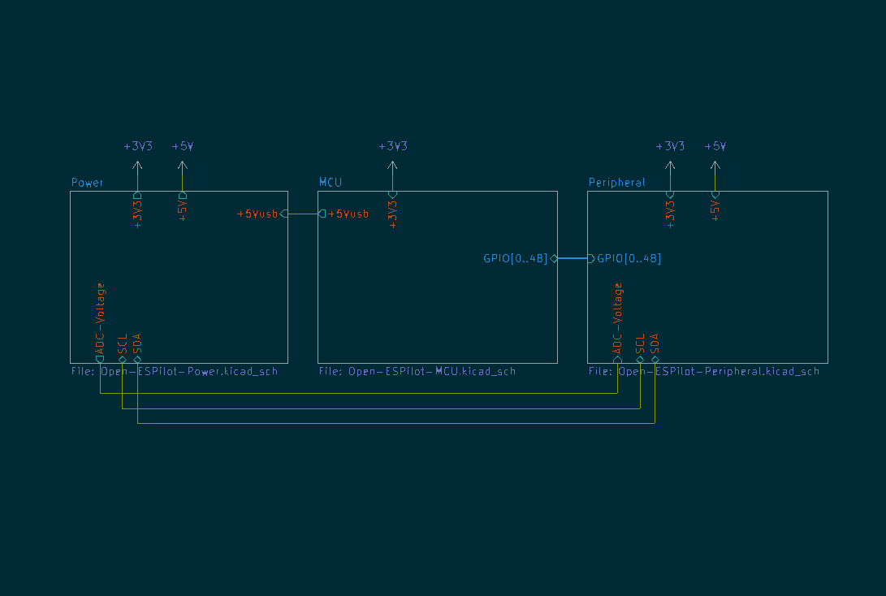
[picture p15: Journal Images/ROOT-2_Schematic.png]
ROOT-2 Schematic
  
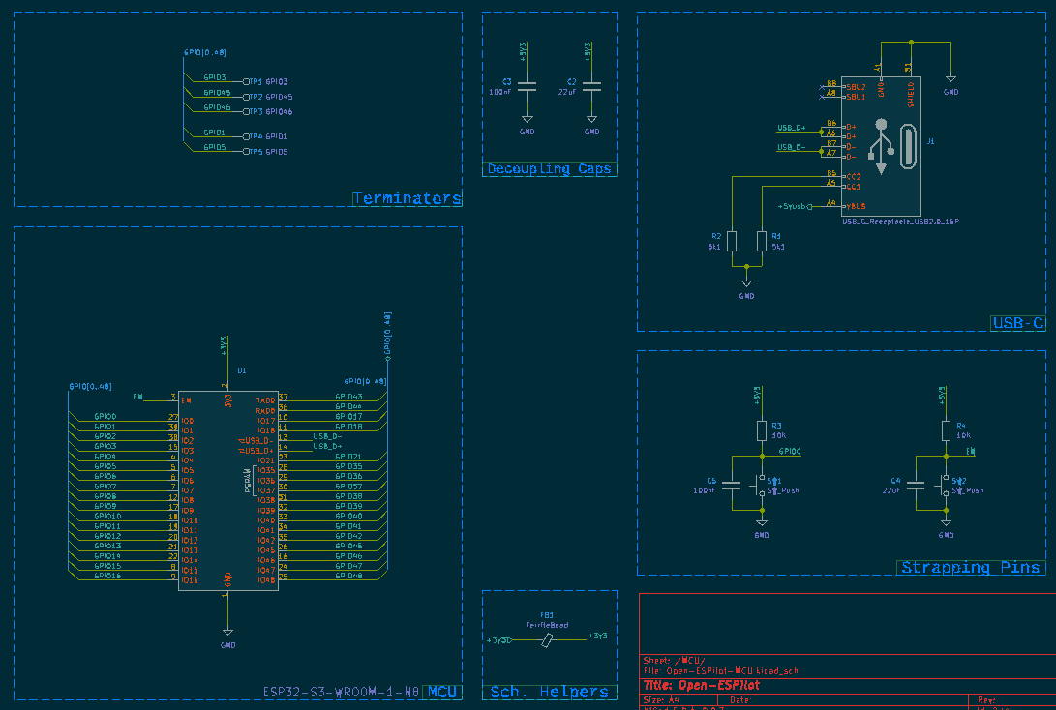
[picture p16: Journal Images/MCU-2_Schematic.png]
MCU-2 Schematic
  
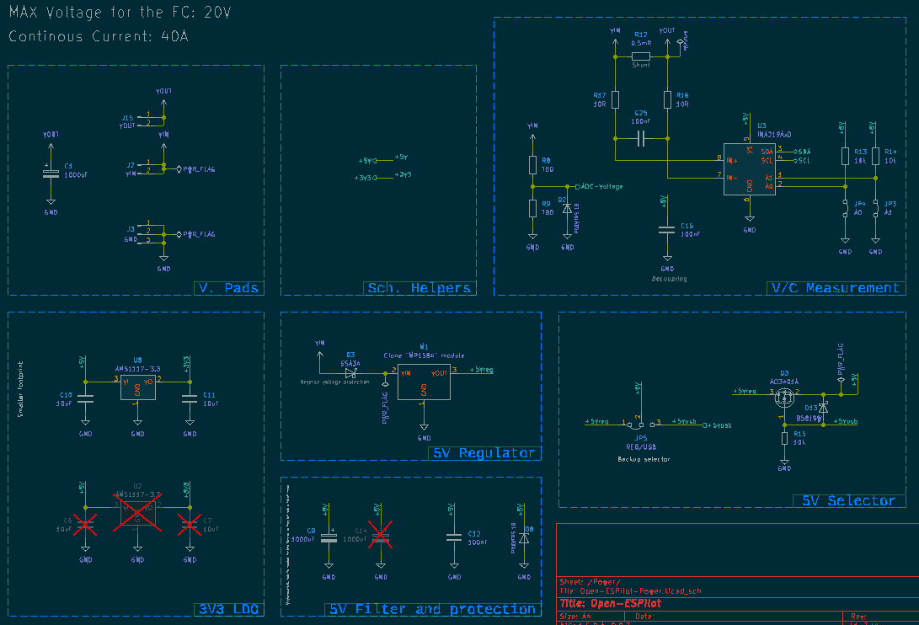
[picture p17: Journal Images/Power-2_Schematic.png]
Power-2 Schematic
  
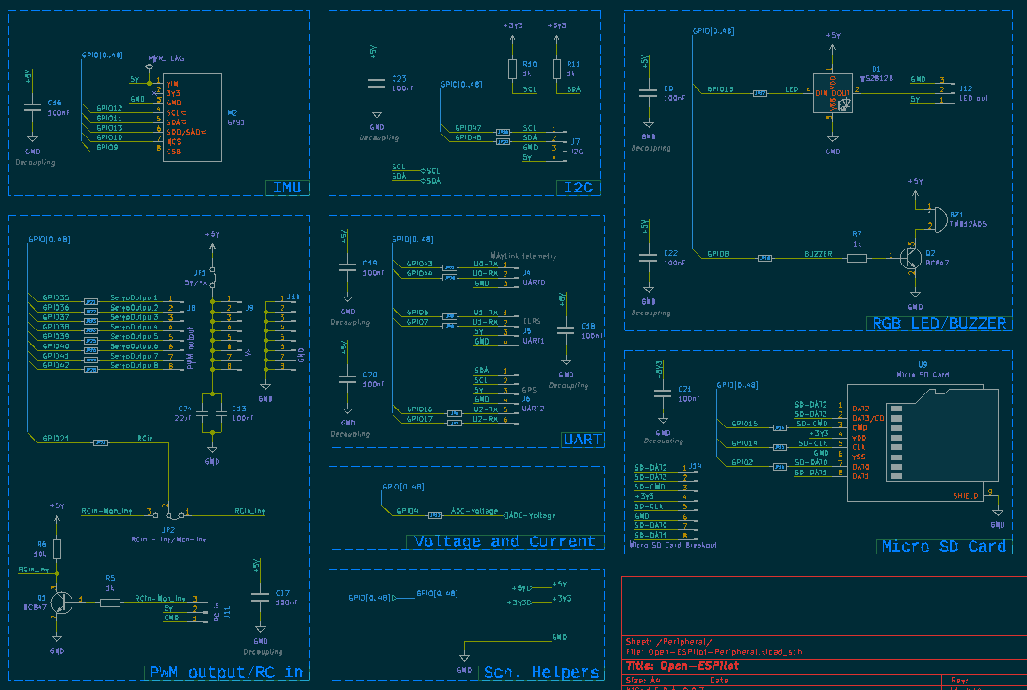
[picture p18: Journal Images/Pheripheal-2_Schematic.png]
Pheripheal-2 Schematic
  

**Time spent: 7h**

## PCB routing and small fixes - 24.7.2025
After checking the schematic I noticed that I forgot to decide on the Voltage divider.  
And I want to reanotate the schematic, so that the components references makes sense.  

Now for the Routing.  
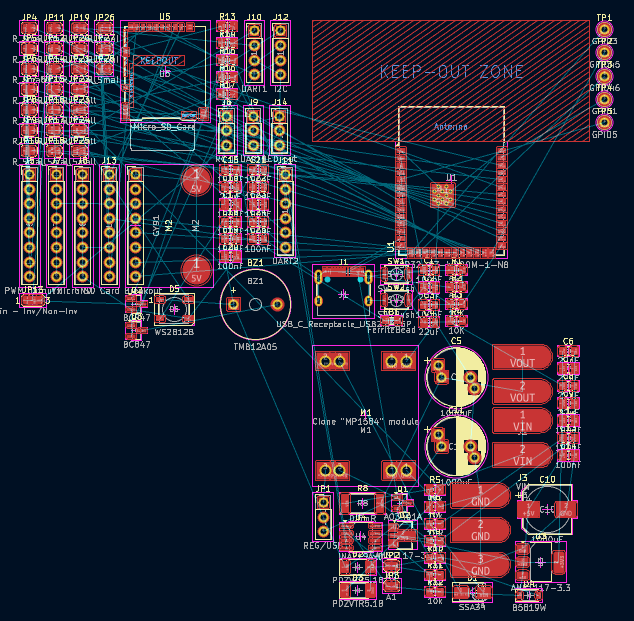
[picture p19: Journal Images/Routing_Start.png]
Routing Start
  
The first thing that I do is to arange the components into function groups and things that should be together.  
PCB Aranged into groups  

Then I went on the power input and measurement.  
Then I have noticed that everything is off-grid so I have manualy entered a rounded up value. But I can't do this to everything grouped so I have decided to remove the components and add them via Updating PCB and with 1mm grid. I will use a 0.1mm grid for everything from now on.  
For now I have put these components to the side as I think a better workflow would be to select the components in schematic and move them in place.  
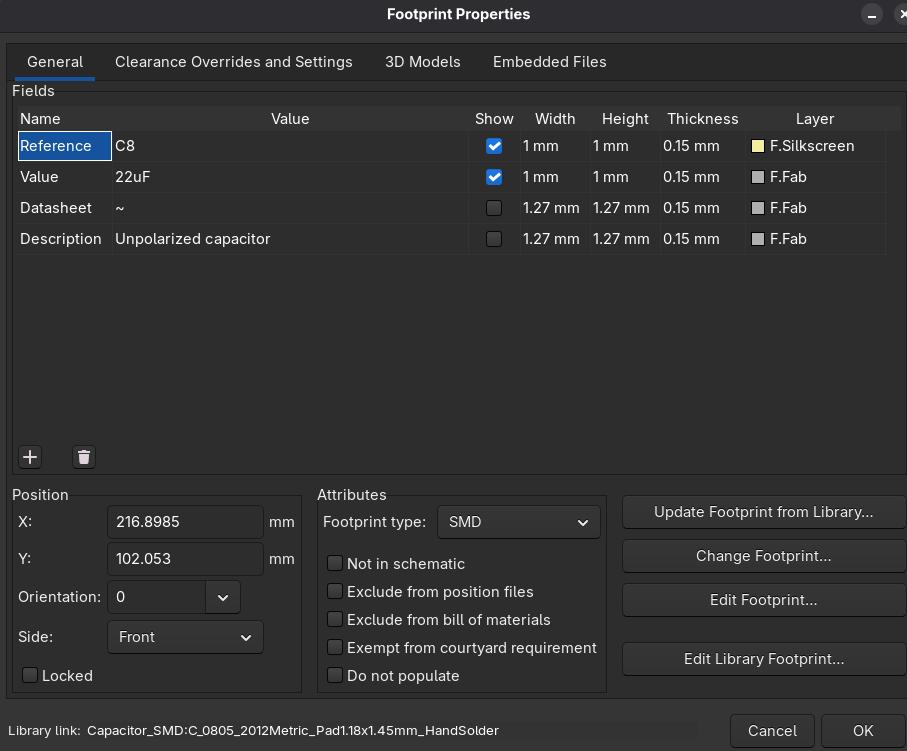
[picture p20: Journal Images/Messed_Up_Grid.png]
Messed Up Grid
  

I have pulled up my layout sketch for reference.  
First thing I worked on is the Power stage as it seemed logical to start from the power input.  
This project also reminds me of my TwinkleTron project which has almost the same layout. 
 - I have aranged the power pads and added coper fill to them to make them electricaly connected. Also a lot of current is going to pass thru those.  
 - Then I've Added the shunt with copper fill and the INA219.  

After that I brought the ESP on top as in my sketch. Because I need to know were the things are going to be roughly positioned. Also added the CC resistors to the USB-C plug. And positioned it to the left side of the ESP.  

Then I went on the PWM output and RC input.  
 - I firstly aligned the PWM headers using the grid. And then merged them.  
 - Under that I routed the RC in header with a invertor.  
After puting them into the top most right corner I noticed that I need to sqeeze in a debug UART headder. So I moved the PWM down.  

The LED, USB-C and buzzer were pretty straight foward.  
 - For the USB-C I just routed the data+/- lines as I already placed the CC resistors.  
 - The LED has just a decouling cap and DIO Headder positioned near the edge of the board.  

Along the way I fixed a few small errors in my schematic.  

**Time spent: 6h**

## PCB routing and small schematic fixes - 26.7.2025
**Its the 26th of July and we are now in Šumava moutains. And I need to finish this project.**  
I've placed the smaller LDO on the front and the bigger one on the back just under the 5V regulator.  
And the voltage measurement on top also on the opposite side of the regulator.  
When working on the PCB I usually notice a few errors and I finalyse some things.  
Like the SD card breakout. The pin headder wouldn't fit and if I stuck with it that would create a lot of issues. So I plan on using the jumpers if I need to check something and I added SMD solder pads to unused pins.  
I saw a space on the right for the UART headers and also the I2C headder.  
After that I've worked on bringing the two sides closer. One being the MCU side and the other on were the power pins.  

Right now I have the local traces routed and the longer traces need to be routed on the back layer.  
Time to finish this project is running short. - its 28.7. And I need to finish it and upload it. All while not having a super relible internet connection.  
If I want internet I neet to go to the local mountain top to get cell connection.  
Then I went on routing the long traces that need to go from one side to the other. Like the Power, I2C, UARTS and Voltage measurement.  
I'm in rush to finish this so I have taken a few shortcuts. Like traces that doesn't run on the same side, traces between headders.  
Maybe I should add a RC filter to the ADC-Voltage.  
To late now.  

And I'm omiting naming the headers as this is supossed to be a early prototype.  
But it should work!  
Only thing remaining is to test the finished board. 

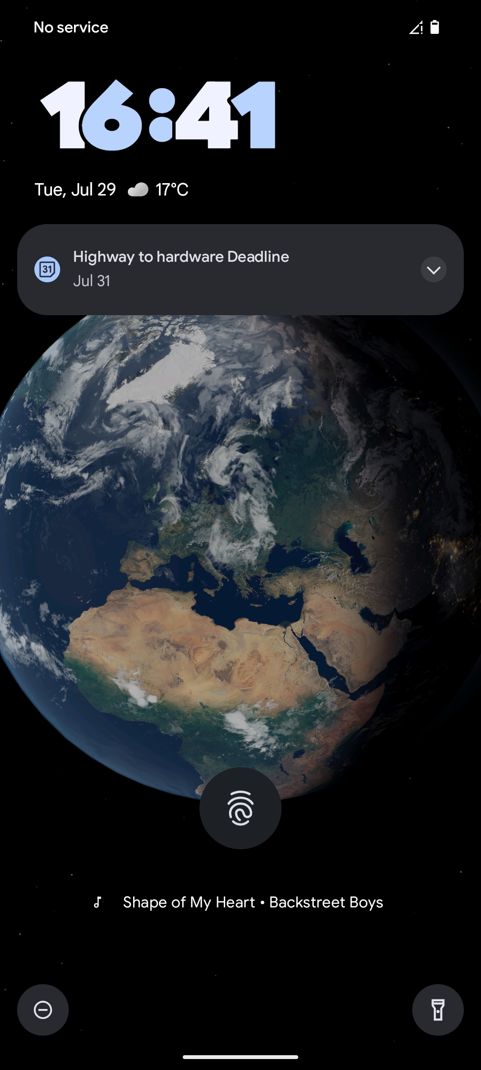
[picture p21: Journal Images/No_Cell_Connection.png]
No Cell Connection
  

And now for the showpiece the render:  
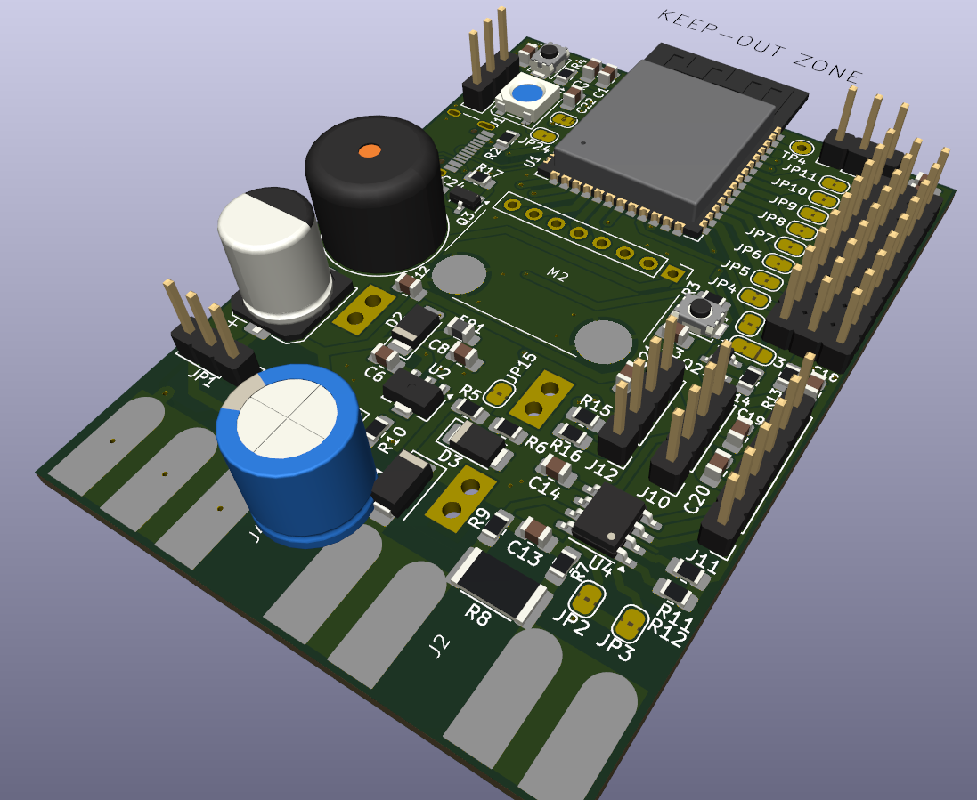
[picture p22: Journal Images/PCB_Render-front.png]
PCB Render -front
  

**Time spent: 6h**

## Finishing documentation and submiting to highway - 30.7.2025
I need to read on how to submit and whats needed. For that I need to visit a place with cell reception as I don't have any internet here.  

I love the highway to hardware only thing is that I would love for the deadline to be mid August as my July is packed. Or I would like to see something like this in the school year.  

I have the README.md describing the project and its goals. And my motivation.  
I've assigned LCSC numbers to parts and made the BOM table in README.md.  
And prepared the README.md for submiting to highway.  
Screenshoted the PCB and added it to RADME.md.  

**Time spent: 4h** - not couting it in total time spent.

## Preparing to order
Yesterday I received the HackClub grant I was the last to be reviewed. And I wasn't shure if I'm going to be accepted.  
Thank a lot for making many student lives better!  

I reviewed it before sending it to be fabricated.  
And I noticed a few things like Headers should be labeled. Apart from that I didn't need to do anything.  
For that I needed to move jumpers and label the ELRS/I2C/GPS Connector.  
When I'm at it I also labeled other things and added cute graphics.  

You may be wondering why did I need to change the connector? It just may be because I was rushing this part. :)  
I thankfully have time now.  

Tomorrow I will order everything.  

**Time spent: 5h**

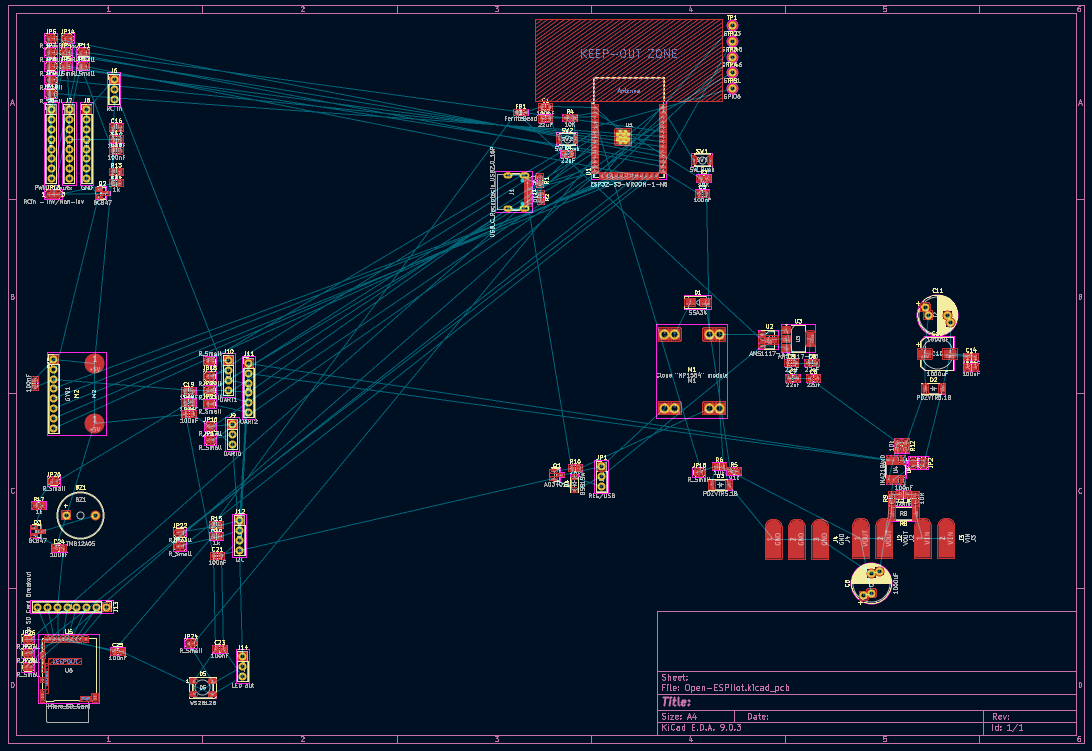
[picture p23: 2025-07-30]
Journal Images/PCB_Arranged_into_groups.png

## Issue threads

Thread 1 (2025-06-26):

Decide on MCU: ESP32 or ESP32-S3?

Tomas-Kuchta-FPV, 2025-06-26:
Trying to choose the main MCU. Should we go with the classic ESP32 or the newer ESP32-S3?
Is ESP32-S3 supported and will it be futureproof.
Would love feedback on performance, features, and future-proofing. What would you pick?

Tomas-Kuchta-FPV, 2025-06-28:
going to use the [ESP32-S3-WROOM-1-N8](https://lcsc.com/product-detail/WiFi-Modules_Espressif-Systems-ESP32-S3-WROOM-1-N8_C2913198.html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) which is $ 5.14.

Tomas-Kuchta-FPV, 2025-06-28:
We have decided on the MCU so now we need to decide on the pinout.
Thanks to Davidbuzz we have a kind of a pin definition cheat file which we can use.
https://github.com/davidbuzz/ardupilot/blob/esp32s3-buzz-combined-sept-11th/libraries/AP_HAL_ESP32/README.esp32s3-pin-selection-hints.txt

Tomas-Kuchta-FPV, 2025-06-30:
The MCU is decided. Now for the pinout tracked in #14.
So I'm closing this issue.

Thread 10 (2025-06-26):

PWM outputs for ESCs/servos

Tomas-Kuchta-FPV, 2025-06-26:
Its probably straight foward.
- Standard ESC Connector
- 6 servo outputs
- Vx that will connect to the onboard BEC and can be cut off via a solder pad.
#9

Tomas-Kuchta-FPV, 2025-07-24:
Got inspired by a generic F405 WING FC. And added decoupling caps to filter the servo noise and a solder jumper thats bridged.

Closed 2025-07-24.

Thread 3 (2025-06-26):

UART Planning

Tomas-Kuchta-FPV, 2025-06-26:
Planned UART use:
1x Telemetry (GCS)
1x GPS
1x Receiver (ELRS)

Can we rely on SoftwareSerial for any extra ports? Or should we avoid it due to performance issues?

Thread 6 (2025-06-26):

Power Monitoring: Voltage Only or Also Current?

Tomas-Kuchta-FPV, 2025-06-26:
Voltage sensing (via divider) will be included.
Is it worth adding a current sensing despite cost and complexity?
How important is current monitoring for our use case?

Tomas-Kuchta-FPV, 2025-07-12:
Measuring current is harder.

There are these methots:
 - Shunt rezistor - generic FCs uses that
 - Hal current senzor
 - INA219 - Easy measurement and sends it via *I2C*
     Isn't implemented in the ardupilot code.

Tomas-Kuchta-FPV, 2025-07-13:
Im going to use a voltage divider and a INA219 to measure current. And the INA219 will be optional

Closed 2025-07-24.

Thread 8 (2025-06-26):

Form Factor and Layout Planning

Tomas-Kuchta-FPV, 2025-06-26:
Aiming for a compact rectangular PCB to simplify mounting.
Trying to balance space, accessibility, and modularity.
Any recommendations for layout dimensions or connector placement?

Closed 2025-07-24.

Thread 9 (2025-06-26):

BEC selection

Tomas-Kuchta-FPV, 2025-06-26:
To lower cost there should be just one BEC that would power the ESPs LDO as well as servos.
Can the BEC be 5V or does anybody need a 7V BEC for servos or VTX?

Tomas-Kuchta-FPV, 2025-06-30:
I have decided on the maximum Voltage that this FC can take. Which is 20V.
In #13

Closed 2025-07-24.

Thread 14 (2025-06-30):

Pinout of the ESP32S3

Tomas-Kuchta-FPV, 2025-06-30:
I'm using a [pinout from Davibuzz](https://github.com/davidbuzz/ardupilot/blob/esp32s3-buzz-combined-sept-11th/libraries/AP_HAL_ESP32/README.esp32s3-pin-selection-hints.txt) for reference.

Tomas-Kuchta-FPV, 2025-06-30:
The pinout is in spreadsheet.
[PCB/Pin Definitions.ods](https://github.com/Tomas-Kuchta-FPV/Open-ESPilot/blob/876b43f05affc29d4abf106bc5316d82eb76f512/PCB/Pin%20Definitions.ods)

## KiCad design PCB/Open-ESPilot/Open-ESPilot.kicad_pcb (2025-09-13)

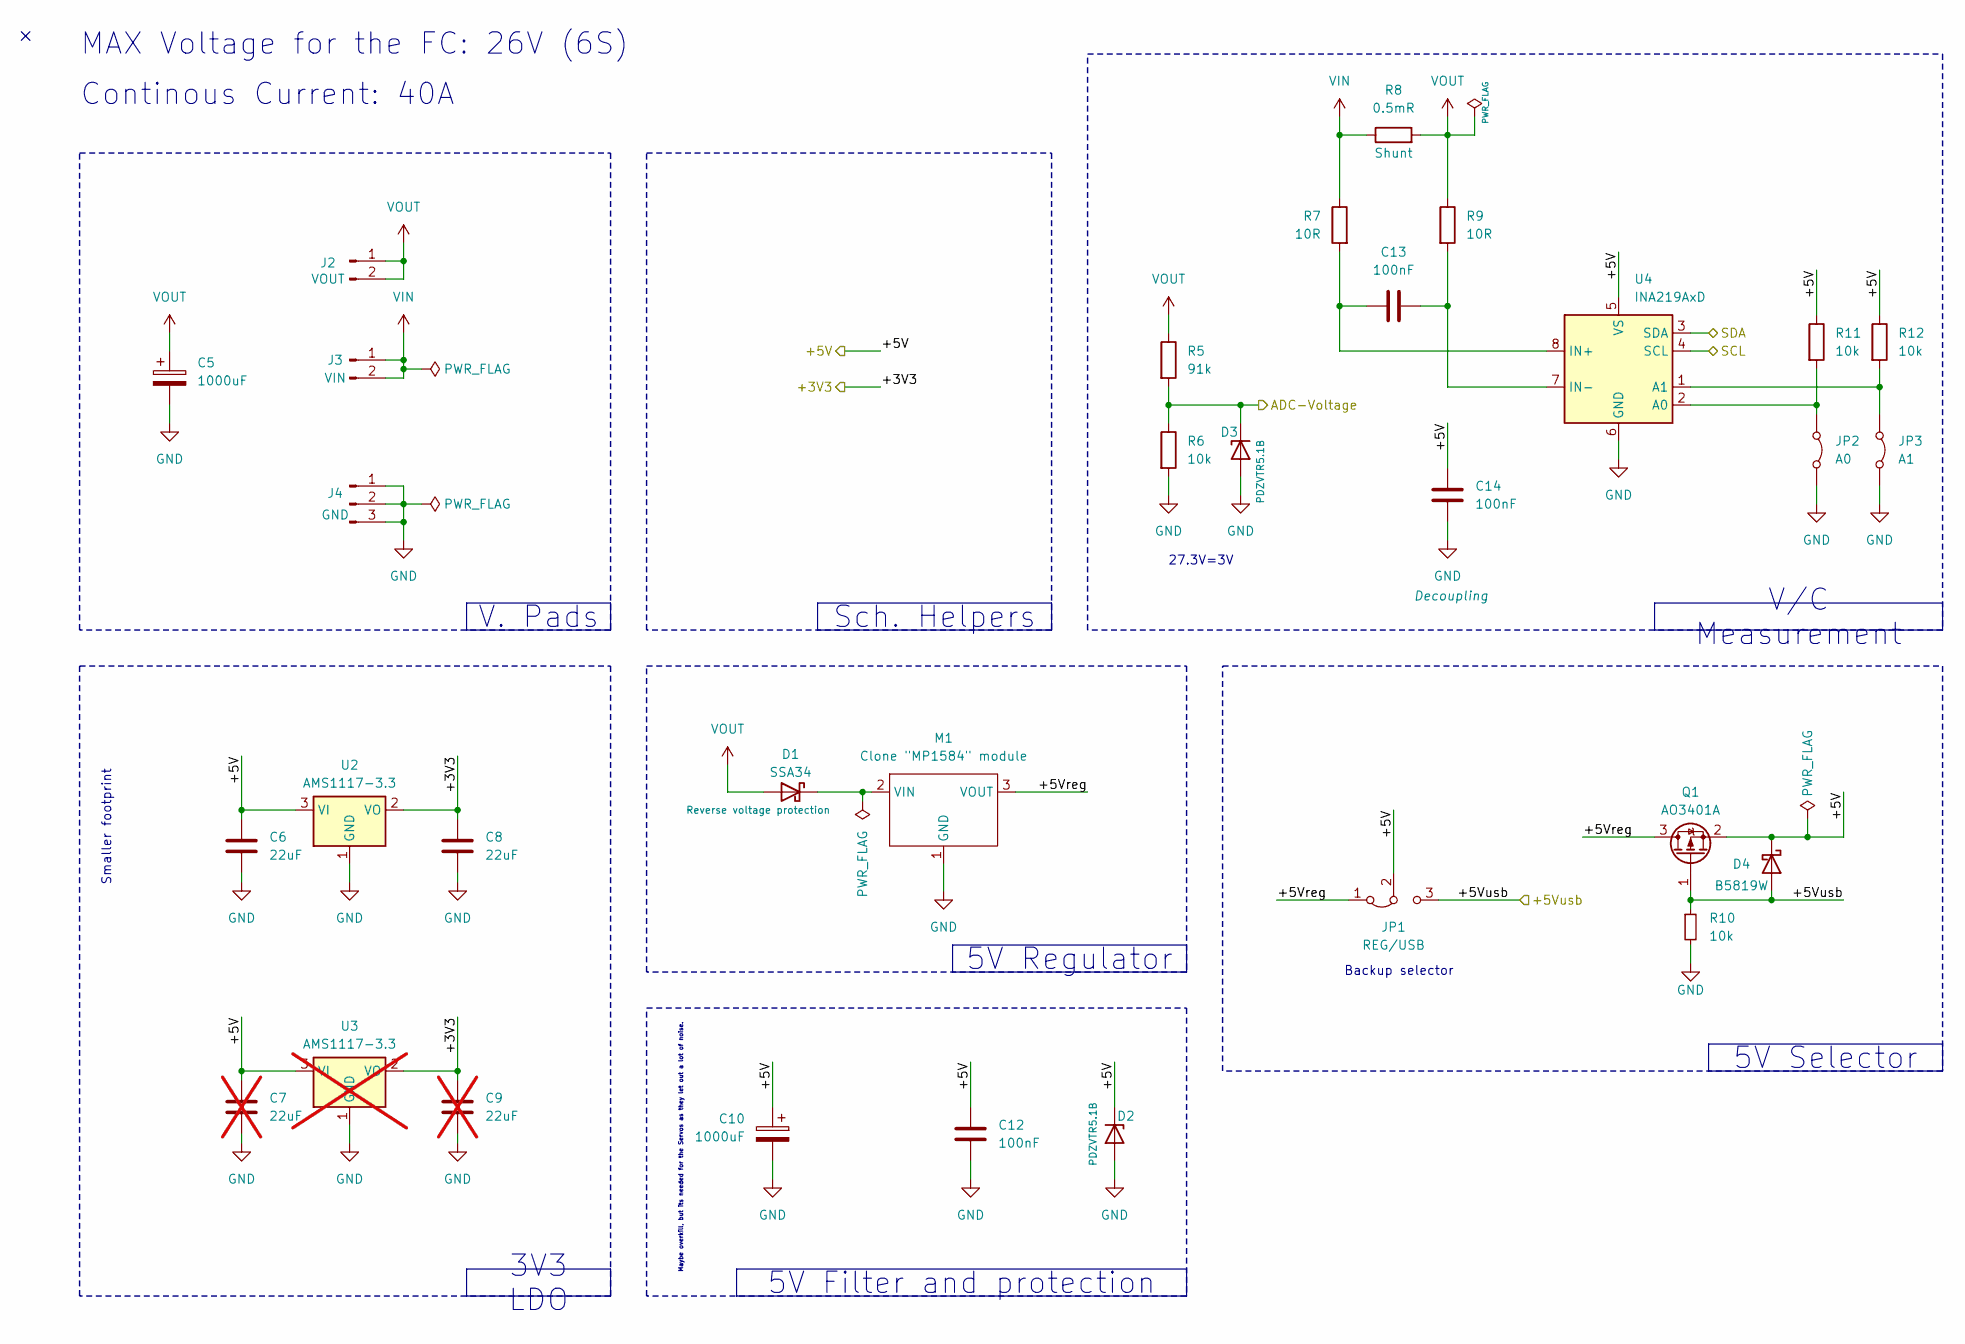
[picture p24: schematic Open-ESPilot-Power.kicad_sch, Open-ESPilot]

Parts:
C5: 1000uF; CP_Radial_D10.0mm_P5.00mm; LCSC C398835
C6, C8: 22uF; C_0805_2012Metric_Pad1.18x1.45mm_HandSolder; LCSC C5674
C7, C9: 22uF; C_0805_2012Metric_Pad1.18x1.45mm_HandSolder; LCSC C5674; not fitted
C10: 1000uF; CP_Elec_8x10; LCSC C311227
C12, C13, C14: 100nF; C_0805_2012Metric_Pad1.18x1.45mm_HandSolder; LCSC C49678
D1: SSA34; D_SMA; LCSC C8678
D2, D3: PDZVTR5.1B; D_SOD-128; LCSC C253499
D4: B5819W; D_SOD-123; LCSC C64885
J2: VOUT; PP_02x
J3: VIN; PP_02x
J4: GND; PP_03x
JP1: REG/USB; PinHeader_1x03_P2.54mm_Vertical
JP2: A0; SolderJumper-2_P1.3mm_Bridged2Bar_RoundedPad1.0x1.5mm
JP3: A1; SolderJumper-2_P1.3mm_Bridged2Bar_RoundedPad1.0x1.5mm
M1: Clone "MP1584" module; Clone _MP1584_ module
Q1: AO3401A; SOT-23; LCSC C15127
R5: 91k; R_0805_2012Metric_Pad1.20x1.40mm_HandSolder; LCSC C84375
R6, R10, R11, R12: 10k; R_0805_2012Metric_Pad1.20x1.40mm_HandSolder; LCSC C84376
R7, R9: 10R; R_0805_2012Metric_Pad1.20x1.40mm_HandSolder; LCSC C96347
R8: 0.5mR; R_2512_6332Metric_Pad1.40x3.35mm_HandSolder; LCSC C37635712
U2: AMS1117-3.3; SOT-89-3; LCSC C880752
U3: AMS1117-3.3; SOT-223-3_TabPin2; LCSC C6186; not fitted
U4: INA219AxD; SOIC-8_3.9x4.9mm_P1.27mm; LCSC C1574856

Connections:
+3V3: C8.1, C9.1, U2.2 (VO), U3.2 (VO); also elsewhere on the board
+5V: C6.1, C7.1, C10.1, C12.1, C14.1, D2.1 (K), D4.1 (K), JP1.2 (C), Q1.2 (S), R11.1, R12.1, U2.3 (VI), U3.3 (VI), U4.5 (VS); also elsewhere on the board
/Peripheral/ADC-Voltage: D3.1 (K), R5.2, R6.1; also elsewhere on the board
/Peripheral/SCL: U4.4 (SCL); also elsewhere on the board
/Peripheral/SDA: U4.3 (SDA); also elsewhere on the board
/Power/+5Vreg: JP1.1 (A), M1.3 (VOUT), Q1.3 (D)
/Power/+5Vusb: D4.2 (A), JP1.3 (B), Q1.1 (G), R10.1; also elsewhere on the board
GND: C5.2, C6.2, C7.2, C8.2, C9.2, C10.2, C12.2, C14.2, D2.2 (A), D3.2 (A), J4.1, J4.2, J4.3, JP2.2 (B), JP3.2 (B), M1.1 (GND), R6.2, R10.2, U2.1 (GND), U3.1 (GND), U4.6 (GND); also elsewhere on the board
unnamed: D1.1 (K), M1.2 (VIN)
unnamed: JP2.1 (A), R11.2, U4.2 (A0)
unnamed: JP3.1 (A), R12.2, U4.1 (A1)
unnamed: C13.1, R7.2, U4.8 (IN+)
unnamed: C13.2, R9.2, U4.7 (IN-)
VIN: J3.1, J3.2, R7.1, R8.1
VOUT: C5.1, D1.2 (A), J2.1, J2.2, R5.1, R8.2, R9.1

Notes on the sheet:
Smaller footprint
MAX Voltage for the FC: 26V (6S)
Continous Current: 40A
Backup selector
Maybe overkill, but its needed for the Servos as they let out a lot of noise.
27.3V=3V
V. Pads
5V Regulator
Sch. Helpers
3V3 LDO
V/C Measurement
5V Filter and protection
5V Selector

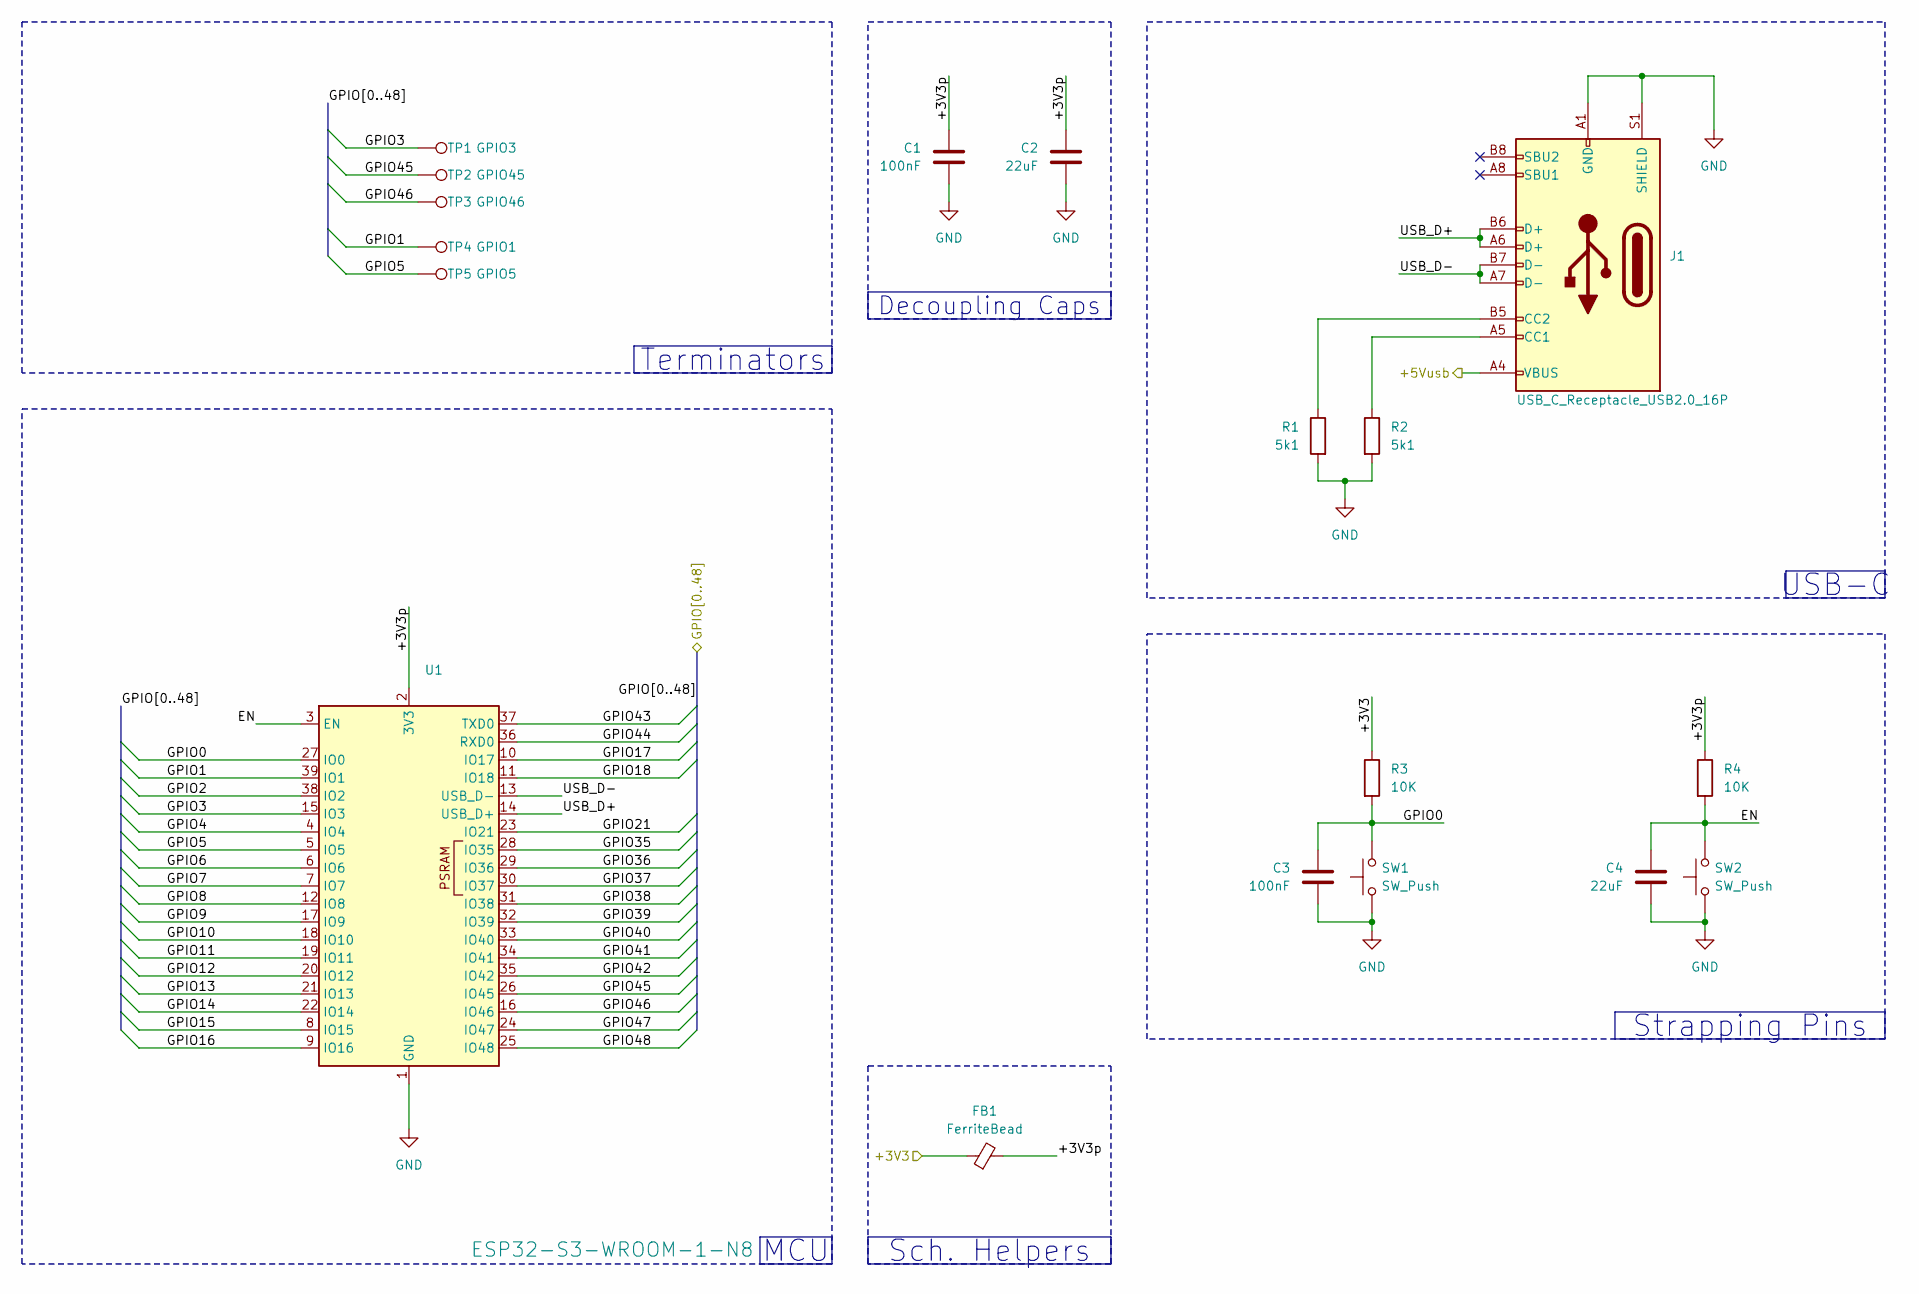
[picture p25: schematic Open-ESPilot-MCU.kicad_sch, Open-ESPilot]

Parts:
C1, C3: 100nF; C_0805_2012Metric_Pad1.18x1.45mm_HandSolder; LCSC C49678
C2, C4: 22uF; C_0805_2012Metric_Pad1.18x1.45mm_HandSolder; LCSC C5674
FB1: FerriteBead; L_0805_2012Metric_Pad1.05x1.20mm_HandSolder; LCSC C15957
J1: USB_C_Receptacle_USB2.0_16P; USB_C_Receptacle_HRO_TYPE-C-31-M-12; LCSC C165948
R1, R2: 5k1; R_0805_2012Metric_Pad1.20x1.40mm_HandSolder; LCSC C84375
R3, R4: 10K; R_0805_2012Metric_Pad1.20x1.40mm_HandSolder; LCSC C84376
SW1, SW2: SW_Push; SW_Push_SPST_NO_Alps_SKRK; LCSC C115357
TP1: GPIO3; TestPoint_Pad_D2.0mm
TP2: GPIO45; TestPoint_Pad_D2.0mm
TP3: GPIO46; TestPoint_Pad_D2.0mm
TP4: GPIO1; TestPoint_THTPad_D2.0mm_Drill1.0mm
TP5: GPIO5; TestPoint_Pad_D2.0mm
U1: ESP32-S3-WROOM-1-N8; ESP32-S3-WROOM-1; LCSC C2913198

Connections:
+3V3: FB1.1, R3.1; also elsewhere on the board
/MCU/+3V3p: C1.1, C2.1, FB1.2, R4.1, U1.2 (3V3)
/MCU/EN: C4.1, R4.2, SW2.2, U1.3 (EN)
/MCU/GPIO0: C3.1, R3.2, SW1.2, U1.27 (IO0)
/MCU/GPIO1: TP4.1, U1.39 (IO1)
/MCU/GPIO2: U1.38 (IO2); also elsewhere on the board
/MCU/GPIO3: TP1.1, U1.15 (IO3)
/MCU/GPIO4: U1.4 (IO4); also elsewhere on the board
/MCU/GPIO5: TP5.1, U1.5 (IO5)
/MCU/GPIO6: U1.6 (IO6); also elsewhere on the board
/MCU/GPIO7: U1.7 (IO7); also elsewhere on the board
/MCU/GPIO8: U1.12 (IO8); also elsewhere on the board
/MCU/GPIO9: U1.17 (IO9); also elsewhere on the board
/MCU/GPIO10: U1.18 (IO10); also elsewhere on the board
/MCU/GPIO11: U1.19 (IO11); also elsewhere on the board
/MCU/GPIO12: U1.20 (IO12); also elsewhere on the board
/MCU/GPIO13: U1.21 (IO13); also elsewhere on the board
/MCU/GPIO14: U1.22 (IO14); also elsewhere on the board
/MCU/GPIO15: U1.8 (IO15); also elsewhere on the board
/MCU/GPIO16: U1.9 (IO16); also elsewhere on the board
/MCU/GPIO17: U1.10 (IO17); also elsewhere on the board
/MCU/GPIO18: U1.11 (IO18); also elsewhere on the board
/MCU/GPIO21: U1.23 (IO21); also elsewhere on the board
/MCU/GPIO35: U1.28 (IO35); also elsewhere on the board
/MCU/GPIO36: U1.29 (IO36); also elsewhere on the board
/MCU/GPIO37: U1.30 (IO37); also elsewhere on the board
/MCU/GPIO38: U1.31 (IO38); also elsewhere on the board
/MCU/GPIO39: U1.32 (IO39); also elsewhere on the board
/MCU/GPIO40: U1.33 (IO40); also elsewhere on the board
/MCU/GPIO41: U1.34 (IO41); also elsewhere on the board
/MCU/GPIO42: U1.35 (IO42); also elsewhere on the board
/MCU/GPIO43: U1.37 (TXD0); also elsewhere on the board
/MCU/GPIO44: U1.36 (RXD0); also elsewhere on the board
/MCU/GPIO45: TP2.1, U1.26 (IO45)
/MCU/GPIO46: TP3.1, U1.16 (IO46)
/MCU/GPIO47: U1.24 (IO47); also elsewhere on the board
/MCU/GPIO48: U1.25 (IO48); also elsewhere on the board
/MCU/USB_D+: J1.A6 (D+), J1.B6 (D+), U1.14 (USB_D+)
/MCU/USB_D-: J1.A7 (D-), J1.B7 (D-), U1.13 (USB_D-)
/Power/+5Vusb: J1.A4 (VBUS), J1.A9 (VBUS), J1.B4 (VBUS), J1.B9 (VBUS); also elsewhere on the board
GND: C1.2, C2.2, C3.2, C4.2, J1.A1 (GND), J1.A12 (GND), J1.B1 (GND), J1.B12 (GND), J1.S1 (SHIELD), R1.2, R2.2, SW1.1, SW2.1, U1.1 (GND), U1.40 (GND), U1.41 (GND); also elsewhere on the board
unnamed: J1.A5 (CC1), R2.1
unnamed: J1.B5 (CC2), R1.1

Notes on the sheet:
USB-C
Strapping Pins
Terminators
Sch. Helpers
MCU
Decoupling Caps

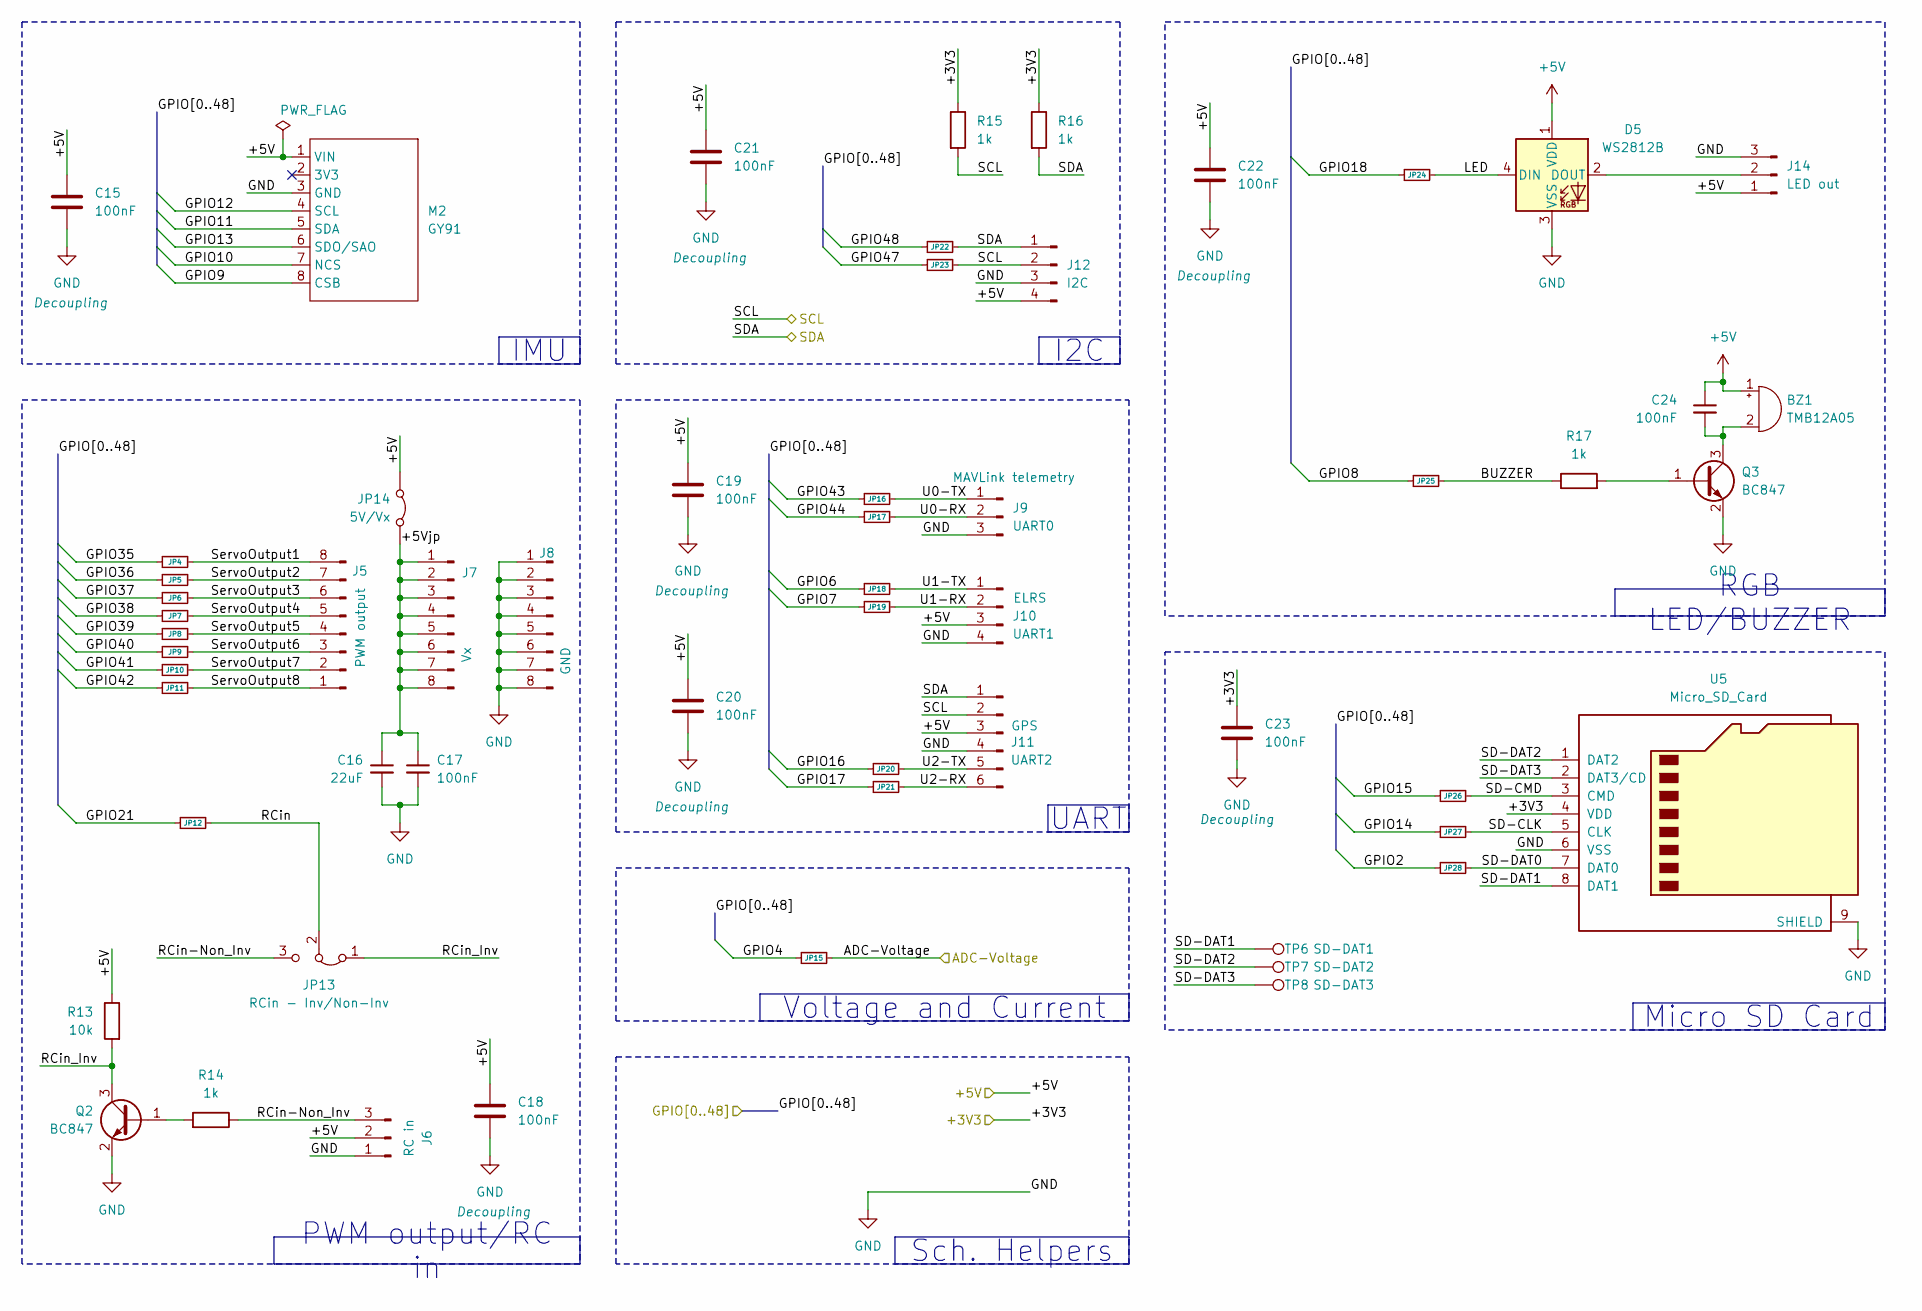
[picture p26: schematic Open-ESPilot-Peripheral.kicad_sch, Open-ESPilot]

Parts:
BZ1: TMB12A05; Buzzer_12x9.5RM7.6; LCSC C96093
C15, C17, C18, C19, C20, C21, C22, C23, C24: 100nF; C_0805_2012Metric_Pad1.18x1.45mm_HandSolder; LCSC C49678
C16: 22uF; C_0805_2012Metric_Pad1.18x1.45mm_HandSolder; LCSC C5674
D5: WS2812B; LED_WS2812B_PLCC4_5.0x5.0mm_P3.2mm; LCSC C2843785
J5: PWM output; PinHeader_1x08_P2.54mm_Vertical
J6: RC in; PinHeader_1x03_P2.54mm_Vertical
J7: Vx; PinHeader_1x08_P2.54mm_Vertical
J8: GND; PinHeader_1x08_P2.54mm_Vertical
J9: UART0; PinHeader_1x03_P2.54mm_Vertical
J10: UART1; PinHeader_1x04_P2.54mm_Vertical
J11: UART2; PinHeader_1x06_P2.54mm_Vertical
J12: I2C; PinHeader_1x04_P2.54mm_Vertical
J14: LED out; PinHeader_1x03_P2.54mm_Vertical
JP4, JP5, JP6, JP7, JP8, JP9, JP10, JP11, JP12, JP15, JP16, JP17, JP18, JP19, JP20, JP21, JP22, JP23, JP24, JP25, JP26, JP27, JP28: R_Small; SolderJumper-2_P1.3mm_Bridged2Bar_RoundedPad1.0x1.5mm
JP13: RCin - Inv/Non-Inv; SolderJumper-3_P1.3mm_Bridged2Bar12_RoundedPad1.0x1.5mm_Num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
JP14: 5V/Vx; SolderJumper-2_P1.3mm_Bridged2Bar_RoundedPad1.0x1.5mm
M2: GY91; GY-91
Q2, Q3: BC847; SOT-23; LCSC C57668
R13: 10k; R_0805_2012Metric_Pad1.20x1.40mm_HandSolder; LCSC C84376
R14, R15, R16, R17: 1k; R_0805_2012Metric_Pad1.20x1.40mm_HandSolder; LCSC C95781
TP6: SD-DAT1; TestPoint_Pad_D2.0mm
TP7: SD-DAT2; TestPoint_Pad_D2.0mm
TP8: SD-DAT3; TestPoint_Pad_D2.0mm
U5: Micro_SD_Card; microSD_HC_Hirose_DM3AT-SF-PEJM5; LCSC C114218

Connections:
+3V3: C23.1, R15.1, R16.1, U5.4 (VDD); also elsewhere on the board
+5V: BZ1.1 (+), C15.1, C18.1, C19.1, C20.1, C21.1, C22.1, C24.1, D5.1 (VDD), J6.2, J10.3, J11.3, J12.4, J14.1, JP14.2 (B), M2.1 (VIN), R13.1; also elsewhere on the board
/MCU/GPIO2: JP28.2; also elsewhere on the board
/MCU/GPIO4: JP15.2; also elsewhere on the board
/MCU/GPIO6: JP18.2; also elsewhere on the board
/MCU/GPIO7: JP19.2; also elsewhere on the board
/MCU/GPIO8: JP25.2; also elsewhere on the board
/MCU/GPIO9: M2.8 (CSB); also elsewhere on the board
/MCU/GPIO10: M2.7 (NCS); also elsewhere on the board
/MCU/GPIO11: M2.5 (SDA); also elsewhere on the board
/MCU/GPIO12: M2.4 (SCL); also elsewhere on the board
/MCU/GPIO13: M2.6 (SDO/SAO); also elsewhere on the board
/MCU/GPIO14: JP27.2; also elsewhere on the board
/MCU/GPIO15: JP26.2; also elsewhere on the board
/MCU/GPIO16: JP20.2; also elsewhere on the board
/MCU/GPIO17: JP21.2; also elsewhere on the board
/MCU/GPIO18: JP24.2; also elsewhere on the board
/MCU/GPIO21: JP12.2; also elsewhere on the board
/MCU/GPIO35: JP4.2; also elsewhere on the board
/MCU/GPIO36: JP5.2; also elsewhere on the board
/MCU/GPIO37: JP6.2; also elsewhere on the board
/MCU/GPIO38: JP7.2; also elsewhere on the board
/MCU/GPIO39: JP8.2; also elsewhere on the board
/MCU/GPIO40: JP9.2; also elsewhere on the board
/MCU/GPIO41: JP10.2; also elsewhere on the board
/MCU/GPIO42: JP11.2; also elsewhere on the board
/MCU/GPIO43: JP16.2; also elsewhere on the board
/MCU/GPIO44: JP17.2; also elsewhere on the board
/MCU/GPIO47: JP23.2; also elsewhere on the board
/MCU/GPIO48: JP22.2; also elsewhere on the board
/Peripheral/+5Vjp: C16.1, C17.1, J7.1, J7.2, J7.3, J7.4, J7.5, J7.6, J7.7, J7.8, JP14.1 (A)
/Peripheral/ADC-Voltage: JP15.1; also elsewhere on the board
/Peripheral/BUZZER: JP25.1, R17.1
/Peripheral/LED: D5.4 (DIN), JP24.1
/Peripheral/RCin: JP12.1, JP13.2 (C)
/Peripheral/RCin-Non_Inv: J6.3, JP13.3 (B), R14.1
/Peripheral/RCin_Inv: JP13.1 (A), Q2.3 (C), R13.2
/Peripheral/SCL: J11.2, J12.2, JP23.1, R15.2; also elsewhere on the board
/Peripheral/SD-CLK: JP27.1, U5.5 (CLK)
/Peripheral/SD-CMD: JP26.1, U5.3 (CMD)
/Peripheral/SD-DAT0: JP28.1, U5.7 (DAT0)
/Peripheral/SD-DAT1: TP6.1, U5.8 (DAT1)
/Peripheral/SD-DAT2: TP7.1, U5.1 (DAT2)
/Peripheral/SD-DAT3: TP8.1, U5.2 (DAT3/CD)
/Peripheral/SDA: J11.1, J12.1, JP22.1, R16.2; also elsewhere on the board
/Peripheral/ServoOutput1: J5.8, JP4.1
/Peripheral/ServoOutput2: J5.7, JP5.1
/Peripheral/ServoOutput3: J5.6, JP6.1
/Peripheral/ServoOutput4: J5.5, JP7.1
/Peripheral/ServoOutput5: J5.4, JP8.1
/Peripheral/ServoOutput6: J5.3, JP9.1
/Peripheral/ServoOutput7: J5.2, JP10.1
/Peripheral/ServoOutput8: J5.1, JP11.1
/Peripheral/U0-RX: J9.2, JP17.1
/Peripheral/U0-TX: J9.1, JP16.1
/Peripheral/U1-RX: J10.2, JP19.1
/Peripheral/U1-TX: J10.1, JP18.1
/Peripheral/U2-RX: J11.6, JP21.1
/Peripheral/U2-TX: J11.5, JP20.1
GND: C15.2, C16.2, C17.2, C18.2, C19.2, C20.2, C21.2, C22.2, C23.2, D5.3 (VSS), J6.1, J8.1, J8.2, J8.3, J8.4, J8.5, J8.6, J8.7, J8.8, J9.3, J10.4, J11.4, J12.3, J14.3, M2.3 (GND), Q2.2 (E), Q3.2 (E), U5.6 (VSS), U5.9 (SHIELD); also elsewhere on the board
unnamed: BZ1.2 (-), C24.2, Q3.3 (C)
unnamed: D5.2 (DOUT), J14.2
unnamed: Q2.1 (B), R14.2
unnamed: Q3.1 (B), R17.2

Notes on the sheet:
Micro SD Card
Voltage and Current
RGB LED/BUZZER
Sch. Helpers
IMU
I2C
UART
PWM output/RC in

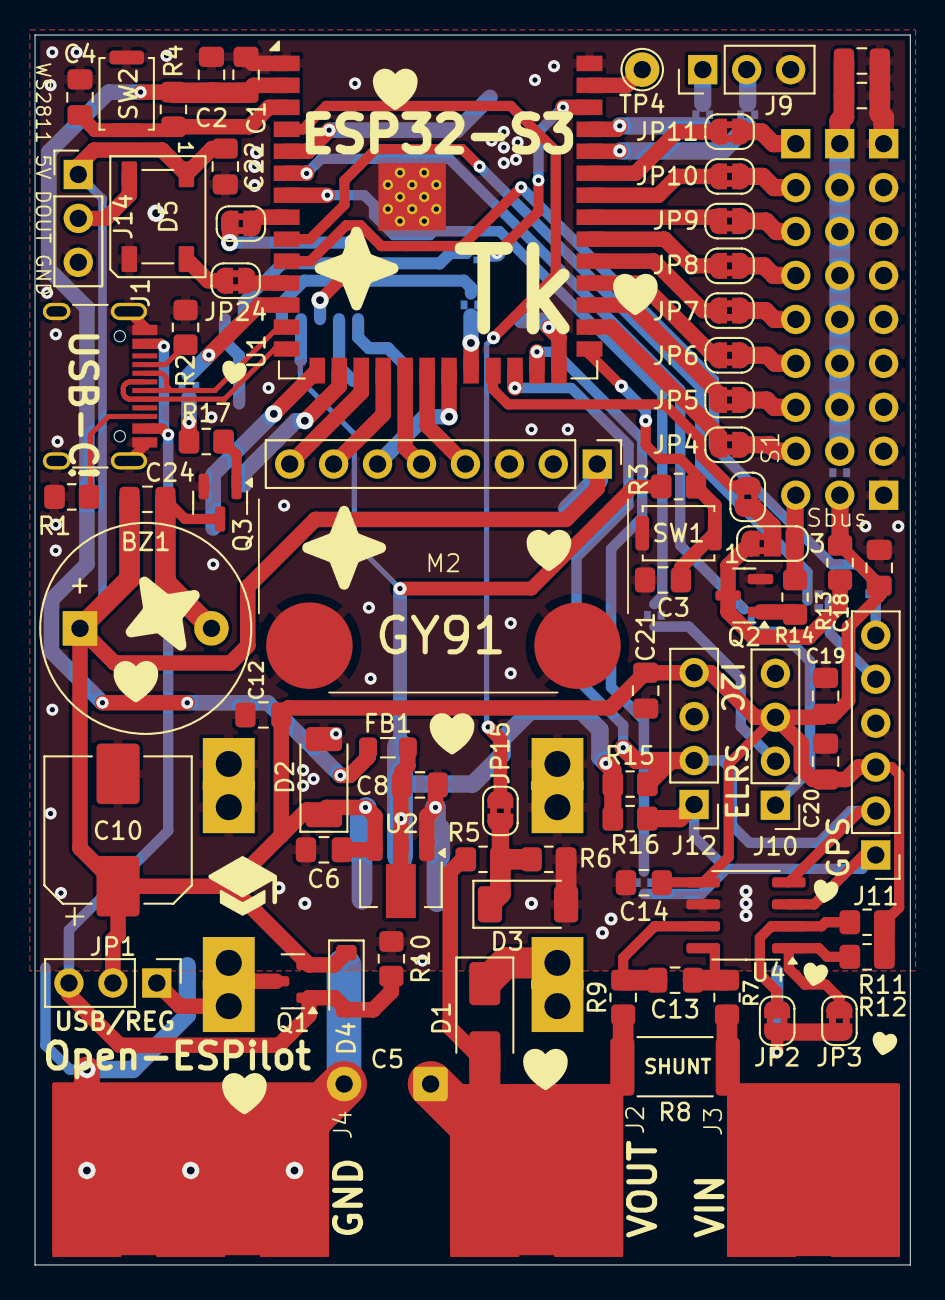
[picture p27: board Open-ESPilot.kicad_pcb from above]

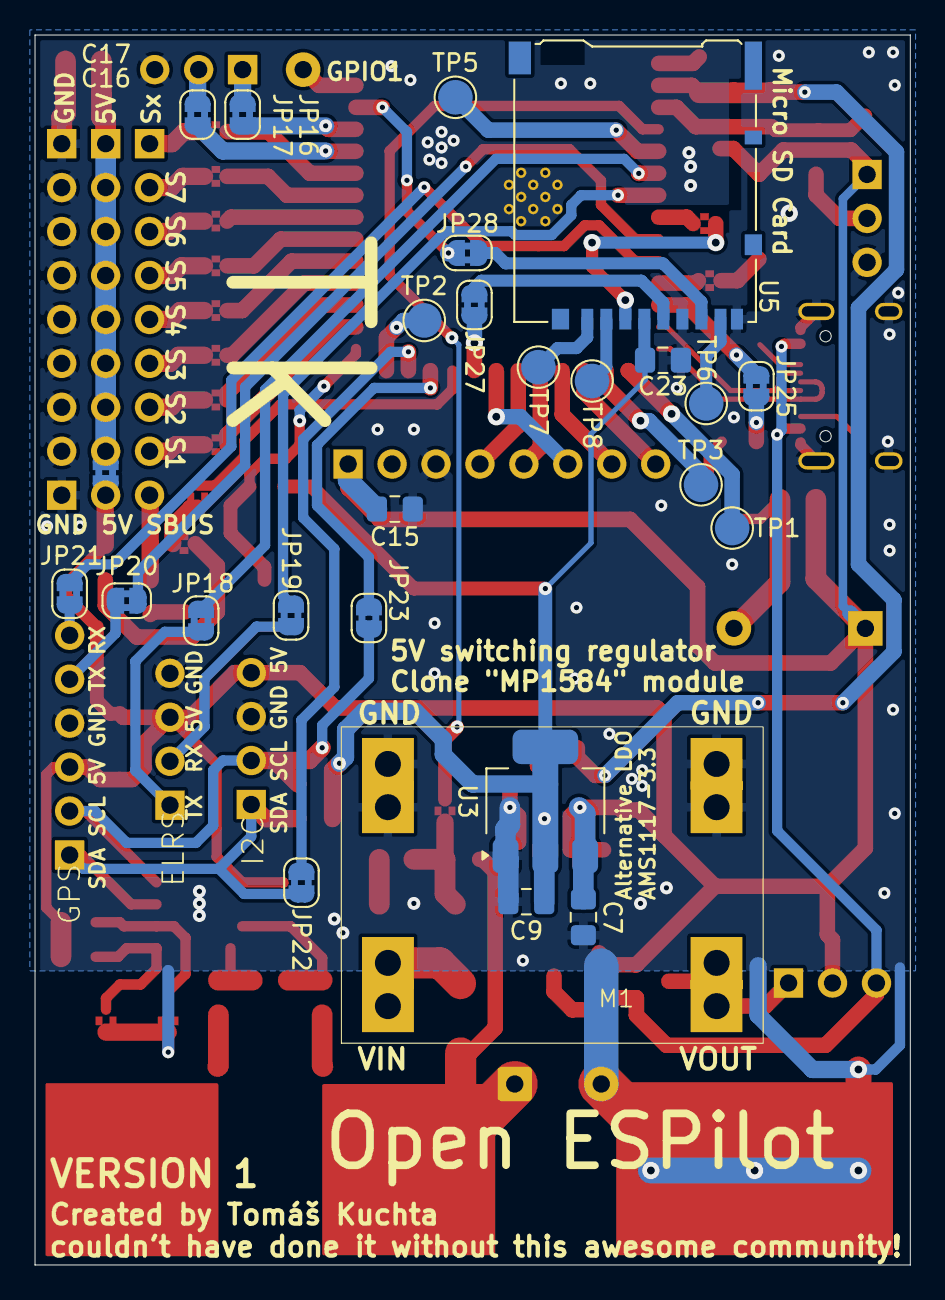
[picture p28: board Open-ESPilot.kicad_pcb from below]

Board: 2 copper layers, 50.6 x 71.1 mm, 108 parts (26 on the bottom side), 85 nets.

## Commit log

2025-06-28 Added basic unfinished schematic for esp32s3 and Pin definitions.
    [Open-ESPilot-MCU.kicad_sch, Open-ESPilot-Power.kicad_sch, Open-ESPilot.kicad_pcb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]
2025-06-30 Finished schematic for the ESP32S3.
    [Open-ESPilot-MCU.kicad_sch, Open-ESPilot.kicad_sch]
2025-06-30 Worked on the Power Schematic. Added voltage input and a switching regulator. Fixed the LDO.
    [Open-ESPilot-Power.kicad_sch]
2025-06-30 Edited Power schematic and insted of the IC I have decided to use modules.
    [Open-ESPilot-Power.kicad_sch]
2025-07-01 Edited the MP1584 module and added Schematic and footprint of the GY-91 and implemented it to the schematic.
    [Open-ESPilot-Peripheral.kicad_sch, Open-ESPilot-Power.kicad_sch, Open-ESPilot.kicad_sch]
2025-07-08 IMU not INS
    [Open-ESPilot-Peripheral.kicad_sch]
2025-07-08 Decided on Pin Assigment
    [Pin Definitions.ods]
2025-07-16 Edited Pin definitions to Open ESPilot. And added the pheripherials to the schematic. Also new journal entry.
    [Open-ESPilot-MCU.kicad_sch, Open-ESPilot-Peripheral.kicad_sch, Open-ESPilot-Power.kicad_sch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]
2025-07-16 Journal and Schematic fixes.
    [Open-ESPilot-Peripheral.kicad_sch]
2025-07-17 Schematic Fixes
    [Open-ESPilot-MCU.kicad_sch, Open-ESPilot-Peripheral.kicad_sch, Open-ESPilot-Power.kicad_sch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]
2025-07-17 more Schematic fixes yay
    [Open-ESPilot-MCU.kicad_sch, Open-ESPilot-Peripheral.kicad_sch, Open-ESPilot-Power.kicad_sch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]
2025-07-19 Fixed spacing.
    [Open-ESPilot-MCU.kicad_sch, Open-ESPilot-Peripheral.kicad_sch]
2025-07-19 Assigned footprints and components for the easy ones (R,C,JP,J)
    [Open-ESPilot-MCU.kicad_sch, Open-ESPilot-Peripheral.kicad_sch, Open-ESPilot-Power.kicad_sch]
2025-07-21 rearenged pins and moved polyfuse.
    [Open-ESPilot-MCU.kicad_sch, Open-ESPilot-Power.kicad_sch, Pin Definitions.ods]
2025-07-24 Added new footprints for power pads and added decoupling capacitors.
    [Open-ESPilot-MCU.kicad_sch, Open-ESPilot-Peripheral.kicad_sch, Open-ESPilot-Power.kicad_sch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]
2025-07-24 Completed the INA219 current sensor schematic. Changed the I2C pullups for a value thats common on board.
    [Open-ESPilot-Peripheral.kicad_sch, Open-ESPilot-Power.kicad_sch]
2025-07-24 Adjusted the Power schematic.
    [Open-ESPilot-Power.kicad_sch]
2025-07-24 Added Ferite bead for the ESP.
    [Open-ESPilot-MCU.kicad_sch]
2025-07-24 Deleted the h. 😅
2025-07-24 Reanotated Schematic.
    [Open-ESPilot-MCU.kicad_sch, Open-ESPilot-Peripheral.kicad_sch, Open-ESPilot-Power.kicad_sch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]
2025-07-24 Decided on voltage divider.
    [Open-ESPilot-Power.kicad_sch]
2025-07-24 PCB init.
    [Open-ESPilot-MCU.kicad_sch, Open-ESPilot-Peripheral.kicad_sch, Open-ESPilot-Power.kicad_sch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]
2025-07-25 Started routing. I have few things there. Fixed schematic.
    [Open-ESPilot-MCU.kicad_sch, Open-ESPilot-Peripheral.kicad_sch, Open-ESPilot-Power.kicad_sch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]
2025-07-27 halve of the PCB is routed.
    [Open-ESPilot-MCU.kicad_sch, Open-ESPilot-Peripheral.kicad_sch, Open-ESPilot-Power.kicad_sch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]
2025-07-29 I'm rushing it! :( Finished the PCB
    [Open-ESPilot-MCU.kicad_sch, Open-ESPilot-Peripheral.kicad_sch, Open-ESPilot.kicad_pcb]
2025-07-30 Added labels to headers.
    [Open-ESPilot.kicad_pcb]
2025-07-30 Selected componets and tried to made a csv.
    [BOM.csv, Open-ESPilot-MCU.kicad_sch, Open-ESPilot-Peripheral.kicad_sch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]
2025-07-30 BOM fix
    [BOM.csv]
2025-08-02 Fixed a BOM oversight.
    [BOM.csv]
2025-08-06 moved BOM.
    [BOM.csv]
2025-09-13 Preparing to order
    [Open-ESPilot.kicad_pcb]
2025-09-22 MOved BOM back to /PCB
2025-10-28 Finished the PCB. And a new Journal entry.
2026-05-13 PCB init of V1.1
